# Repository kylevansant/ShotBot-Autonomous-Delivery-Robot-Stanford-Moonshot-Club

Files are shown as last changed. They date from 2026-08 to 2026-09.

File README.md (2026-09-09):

# ShotBot

**Stair-Climbing Robotic Delivery Platform**  
Developed through the Stanford Moonshot Club

ShotBot is a team-developed mechatronics project focused on building a mobile delivery robot capable of traversing stairs. The project began as a broader autonomous-delivery concept, originally called **SCARD — Stair Climbing Autonomous Robot Delivery**, and evolved into a working prototype centered on the core mechanical and electrical challenges of stair climbing.

The completed platform combines a tracked drivetrain, an articulated front stair-climbing mechanism, custom mechanical components, a custom electrical interconnect PCB, and ESP32-based motor control. The final prototype is operated with a Bluetooth gamepad and demonstrates controlled driving and functional stair climbing. Autonomous navigation, LiDAR-based perception, and additional sensing were investigated during development but were not integrated into the final operating system.

The repository documents the full engineering process, including mechanical design, electrical architecture, embedded firmware, design references, prototype testing, and development history.

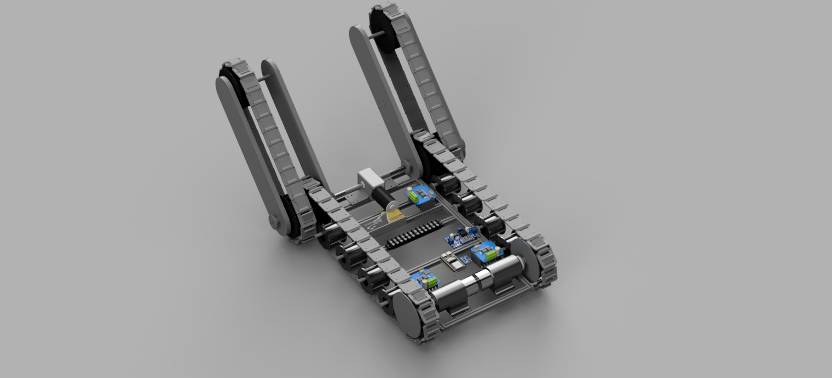
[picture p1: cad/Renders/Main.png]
ShotBot CAD render


## Demonstration

The final prototype successfully demonstrated the primary goal of the project: climbing a staircase using its tracked drivetrain and articulated front mechanism.

https://github.com/user-attachments/assets/51ea6069-b447-48b8-9718-07221bc402e1

Additional development and testing footage is available in the [`media/`](media/) directory.

## Mechanical Design

The mechanical system was designed primarily in Autodesk Fusion 360. ShotBot uses a tracked drivetrain together with an articulated front mechanism intended to improve engagement with stair surfaces and assist the robot during transitions onto and off of a staircase.

Mechanical development included the main chassis, drivetrain components, sprockets, tread elements, motor mounts, front flipper components, sensor mounting concepts, and multiple design revisions retained in the repository to document the evolution of the system.

The repository includes native Fusion 360 assembly files, STEP exports, custom-part models, and rendered views of the completed assembly.

For detailed mechanical documentation, see the [`cad/`](cad/) directory.

## Electrical System

ShotBot is powered by a 3S LiPo battery and uses three independent BTS7960 motor-driver channels controlled by an ESP32 DevKit. The electrical system separates the high-current motor-power paths from the low-voltage control electronics and uses individually fused branches for the major loads.

The system was developed incrementally, beginning with breadboard-based integration and subsystem testing before being consolidated into a custom interconnect PCB designed in Altium Designer. The final PCB was fabricated, installed on the robot, and used successfully during operation.

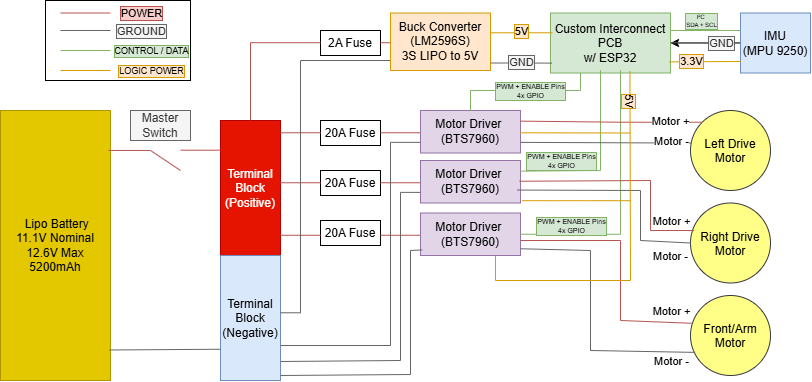
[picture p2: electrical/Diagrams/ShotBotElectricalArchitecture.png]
ShotBot electrical architecture


The electrical architecture above shows the relationship between the battery, fused power-distribution branches, buck-converted logic supply, ESP32 controller, motor drivers, and sensor interfaces used in the final prototype.

The custom PCB organizes the interfaces between the ESP32, motor drivers, IMU, and low-voltage power system while reducing point-to-point wiring in the final prototype.

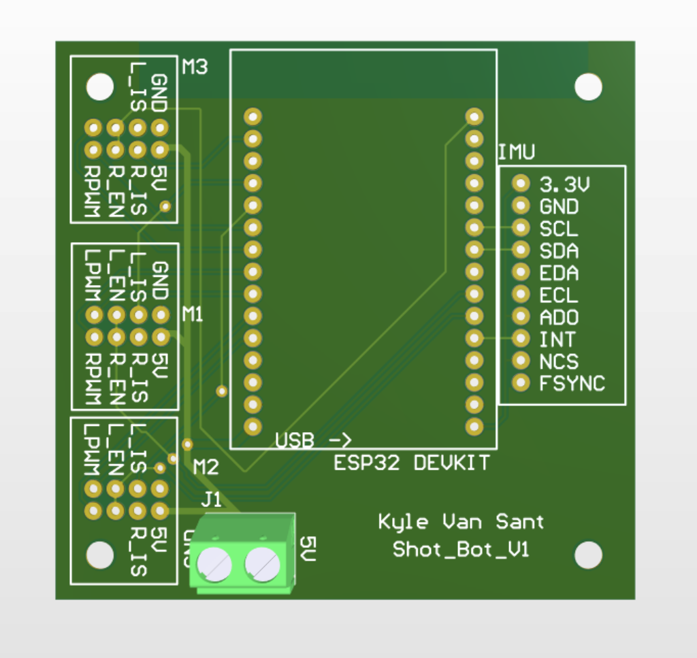
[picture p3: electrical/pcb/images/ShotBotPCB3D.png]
ShotBot PCB render


For schematics, PCB source files, Gerbers, photographs, and additional electrical documentation, see the [`electrical/`](electrical/) directory.

## Firmware and Control

The final robot is controlled by an ESP32 using firmware written with the Arduino framework. Bluetooth gamepad support is provided through Bluepad32.

The firmware independently controls the left drivetrain motor, right drivetrain motor, and front stair-climbing motor through three BTS7960 H-bridges. Tank-style joystick control is used for the drivetrain, while the front mechanism is controlled independently from the gamepad shoulder buttons.

The final control software also includes PWM output limits, joystick deadzone handling, motor-driver enable control, and controller-disconnect fail-safe behavior. The firmware in the repository is the integrated code used on the working prototype rather than the temporary subsystem-test sketches used during development.

For the final control code and implementation details, see the [`firmware/`](firmware/) directory.

## Testing and Prototype Development

ShotBot was developed through repeated subsystem and integration testing rather than as a single final build. Testing included individual motor operation, tread behavior, drivetrain motion, front-mechanism control, electrical integration, controller operation, sensor experiments, and stair-climbing trials.

The [`media/`](media/) directory contains video documentation from these stages of development. This footage is retained to show the progression from early component testing through the completed stair-climbing prototype.

The [`tests/`](tests/) directory is reserved for project testing documentation and related material.

## Project Documentation

Supporting project records are maintained in the [`docs/`](docs/) directory. These include the project bill of materials, the original SCARD project pitch, and technical references used during development.

One of the primary design references was the 2023 IEEE Access review *Stair-climbing Robots: a Review on Mechanism, Sensing, and Performance Evaluation*. Its discussion of tracked stair-climbing architectures and articulated flippers helped inform the team's investigation of a tracked platform with a front articulated mechanism.

The original SCARD presentation is retained as historical documentation because it captures the initial project goals, including autonomous navigation, LiDAR sensing, camera integration, stair climbing, and delivery functionality. The final ShotBot prototype intentionally represents a narrower completed scope focused on the mechanical platform, electrical integration, embedded motor control, and reliable stair-climbing operation.

## Repository Organization

The major project sections are organized as follows:

- [`cad/`](cad/) — mechanical CAD, custom parts, assembly files, and renders
- [`electrical/`](electrical/) — electrical architecture, PCB design, fabrication files, and physical implementation
- [`firmware/`](firmware/) — final ESP32 control firmware and control-system documentation
- [`docs/`](docs/) — project records, bill of materials, original pitch, and design references
- [`media/`](media/) — development, testing, and final demonstration footage

Each major engineering section contains its own README with more detailed technical documentation.

## Team

ShotBot was developed as a team project through the Stanford Moonshot Club.

- **Kyle Van Sant** — Project Lead
- **Joshua Nangle** — Mechanical Lead
- **Gabriel Irazabal** — Electrical Lead
- **Griffin Wright** — Dynamics & Analysis Lead

## Project Status

ShotBot reached the working-prototype stage as a remotely controlled stair-climbing delivery platform. The completed system demonstrated integrated mechanical, electrical, and embedded-control functionality, including independent drivetrain control, operation of the front stair-climbing mechanism, and successful stair traversal.

More advanced autonomy concepts were explored during the project, including LiDAR, IMU feedback, and sensor mounting, but were not incorporated into the final operating prototype.

## Development History

The project began as **SCARD — Stair Climbing Autonomous Robot Delivery**, a concept for a delivery robot intended to combine autonomous navigation with the ability to move between floors using conventional stairs.

Early development focused on understanding existing stair-climbing robot architectures and identifying a mechanism that could be manufactured within the team's available resources. Research into tracked robots and articulated flipper systems helped guide the mechanical direction of the project.

From there, development progressed through mechanical CAD and prototype fabrication, drivetrain and tread testing, electrical breadboarding, ESP32 motor-control development, custom PCB design, controller integration, and full-system testing. LiDAR and IMU hardware were also investigated as part of the original sensing and autonomy direction.

As the project matured, the team narrowed the final scope to prioritize completion of a reliable physical platform. The resulting ShotBot prototype used Bluetooth teleoperation rather than autonomous navigation, while retaining the tracked stair-climbing architecture and integrated electrical system developed through the project.

The final stage of development demonstrated the complete robot driving under remote control and successfully climbing stairs, validating the primary mechanical objective that motivated the project.

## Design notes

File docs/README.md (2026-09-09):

# ShotBot Project Documentation

This directory contains supporting project-level documentation for **ShotBot**, a stair-climbing delivery robot developed as part of the Stanford Moonshot Club.

Detailed mechanical, electrical, and firmware documentation is maintained in their respective directories. This folder contains broader project records, including procurement information, historical planning material, and technical references that informed the design.

---

## Bill of Materials and Project Costs

[`Shotbot_BOM.xlsx`](Shotbot_BOM.xlsx)

This spreadsheet contains component procurement and cost records accumulated throughout ShotBot development.

It includes:

- Major mechanical and electrical components
- Component quantities and purchase costs
- Supplier and product references
- Prototype cost tracking
- Components used during earlier design iterations
- Components considered for future revisions

Because the spreadsheet was maintained throughout the development process, some listed components were replaced, removed from the final design, or never incorporated into the completed prototype.

The document is retained as a record of the project's hardware selection, procurement, and iterative development process.

---

## Original SCARD Project Pitch

[`scard_original_project_pitch.pdf`](scard_original_project_pitch.pdf)

This presentation reflects the team's original project concept and intended scope during the early development of ShotBot.

The project was initially proposed as **SCARD — Stair Climbing Autonomous Robot Delivery**. The original concept included planned capabilities such as:

- Autonomous navigation
- LiDAR-based environmental sensing
- Camera integration
- Stair climbing
- Tracked locomotion
- Item transportation

As development progressed, the project scope was narrowed to prioritize the mechanical stair-climbing system, electrical integration, and completion of a reliable working prototype.

The completed ShotBot platform therefore used **Bluetooth teleoperation rather than autonomous navigation**.

The presentation is retained as historical documentation of the project's original goals and design direction and should not be interpreted as a description of the final implemented system.

---

## Design References

The following literature was used during development to evaluate existing approaches to stair-climbing robotics and inform the mechanical architecture of ShotBot.

### Stair-Climbing Robot Mechanisms

[`References/stair_climbing_robots_review.pdf`](References/stair_climbing_robots_review.pdf)

**T. Seo, S. Ryu, J. H. Won, Y. Kim, and H. S. Kim,  
"Stair-climbing Robots: a Review on Mechanism, Sensing, and Performance Evaluation,"  
IEEE Access, 2023.  
DOI: 10.1109/ACCESS.2023.3286871**

This review surveys several major classes of stair-climbing robots, including:

- Tracked robots
- Legged robots
- Wheel-linkage robots
- Wheel-legged robots

The paper was particularly relevant to the development of ShotBot's **tracked stair-climbing architecture**.

Its discussion of one-body tracked robots with articulated flippers helped inform the decision to use a front articulated mechanism in conjunction with the main tracks. The reviewed mechanisms demonstrate how flippers can increase track contact with stairs, assist with transitions onto and off of staircases, and reduce the risk of tip-over during stair traversal.

The ShotBot design was subsequently adapted around the project's own mechanical requirements, available actuators, manufacturing methods, and prototype constraints.

This reference is included to document the prior research that informed the team's mechanical design decisions rather than as work produced by the ShotBot team.

The included author version is distributed under the **Creative Commons Attribution-NonCommercial-NoDerivatives 4.0 International License** and is retained unmodified. :contentReference[oaicite:0]{index=0}

---

## Project Evolution

ShotBot changed significantly between the initial proposal and the completed prototype.

The general project progression was:

```text
Original SCARD Concept
        │
        │  Autonomous stair-climbing delivery robot
        │
        ▼
Mechanical Architecture Development
        │
        │  Tracked locomotion + articulated stair mechanism
        │
        ▼
Electrical Prototyping
        │
        │  Breadboard testing + ESP32 motor control
        │
        ▼
Custom PCB Integration
        │
        │  Altium-designed interconnect PCB
        │
        ▼
Final ShotBot Prototype
        │
        │  Bluetooth teleoperation
        │  Independent motor control
        │  Functional stair climbing
        ▼
Working Prototype
```

Autonomous navigation, LiDAR integration, and camera-based perception remained part of the original design direction but were not implemented in the final version due to project scope.

The project instead focused on successfully demonstrating the mechanical and electrical systems required for a remotely operated stair-climbing delivery platform.

---

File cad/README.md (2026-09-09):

# ShotBot CAD

This directory contains the mechanical design files for **ShotBot**, a stair-climbing delivery robot developed through the Stanford Moonshot Club.

The mechanical system was designed primarily in Autodesk Fusion 360 and developed through repeated prototyping and testing. The final architecture uses a tracked differential-drive base combined with a pair of articulated tracked front flippers. The flippers are mechanically synchronized and are used to control how the robot engages with and transitions onto stairs.

Native Fusion 360 assemblies, STEP exports, custom part files, and rendered views are included to document both the final configuration and the design iterations that led to it.

## Main Assembly

ShotBot main assembly render

The final mechanical assembly combines three major subsystems:

- A left and right tracked drivetrain for normal driving and differential steering
- Two articulated front flippers with their own tracked loops
- A shared flipper-actuation system that rotates both front arms together

The design was intended to keep the stair-climbing mechanism mechanically simple while allowing the front of the robot to change geometry during stair approach and transition.

## Mechanical Architecture

### Main Tracked Drivetrain

ShotBot uses two independent main track loops, one on each side of the chassis.

Each side is powered by a rear drive motor connected to the rear sprocket. The front and rear sprockets are the same diameter, while the rear sprocket functions as the driven sprocket. The remaining sprockets and rollers support and guide the track.

Independent left and right drive control allows the robot to use tank-style steering on flat surfaces.

Track tension is set primarily by the spacing of the sprockets and rollers rather than by a separate active tensioning mechanism.

### Articulated Front Flippers

The front of the robot uses two tracked flipper arms, one on each side.

The left and right flippers are mechanically linked and rotate together. A dual-shaft worm-gear motor drives two rods extending toward the left and right sides of the chassis. These rods are connected through shaft couplers to the flipper assemblies.

Using one motor to control both flippers kept the two sides synchronized and reduced the amount of independent actuation hardware required.

The worm-gear drive also provided a compact method for producing the torque needed to reposition the flippers while keeping the actuation system inside the chassis.

### Coupled Track System

The main drivetrain track and the flipper track are implemented as two separate loops on each side of the robot.

The loops are mechanically coupled through the shared front sprocket geometry. When the main drive motor powers the base track, rotation at the front sprocket also drives the track around the articulated flipper.

This means the flipper tracks do not require separate drive motors. The rear drive motor provides propulsion for both the main track loop and the flipper track loop, while the front worm-gear motor changes only the angular position of the flipper arms.

This separation between **track propulsion** and **flipper articulation** was one of the central mechanical features of the design.

## Stair-Climbing Sequence

The stair-climbing process relies on coordinated use of the drive tracks and front flippers.

At a high level, the sequence is:

1. The robot approaches the staircase using the main drivetrain.
2. The flippers are positioned to engage the first stair.
3. The main tracks continue driving forward, which also drives the flipper track loops.
4. The flippers are rotated as needed to help lift and guide the front of the chassis onto the staircase.
5. Once the main tracks establish contact with the stairs, the robot continues climbing using the combined track contact area.
6. The flippers can be repositioned again during the final transition off the staircase.

The tracked flippers increase the effective contact geometry at the front of the robot and help reduce the abrupt transition that would otherwise occur between flat-ground driving and stair engagement.

## Track Support Rollers

The support rollers underneath the chassis became one of the most important parts of the mechanical design.

The printed tracks deform under the weight of the robot. Without sufficient support, the track can deflect upward enough for the chassis itself to contact the edge of a stair. The rollers provide intermediate support underneath the track so that the robot's weight is carried through the track and roller system rather than directly by the chassis.

This subsystem required significant iteration. Approximately four to five roller-holder designs were tested before reaching a configuration that could support the robot without excessive bending or failure.

The roller holders therefore represent a relatively small part geometrically, but they were critical to making the final stair-climbing system function reliably.

## Mechanical Development and Iteration

The final design was the result of repeated mechanical revisions rather than a single CAD pass.

Several areas required substantial iteration during development.

### Roller Holders

Early roller-holder designs were not stiff enough to support the chassis loads generated during stair climbing. Some versions bent or failed under the robot's weight.

Multiple revisions were made to improve stiffness, load transfer, and support of the track until the roller system could reliably keep the chassis clear of the stair edges.

### Shaft Couplers

Early couplers were 3D printed and used a snap-style attachment concept.

These parts were unable to transfer sufficient torque reliably. Under load, the couplers could slip rather than maintaining a rigid connection between the motor-driven shaft and the mechanism.

The coupler design therefore became an important mechanical limitation and was revised as the system developed.

### Sprocket Interfaces

Several sprocket versions were developed with different attachment methods to the drive shafts and couplers.

The main challenge was not the sprocket geometry itself, but creating a connection that could transmit drivetrain torque reliably while remaining manufacturable with the tools and materials available to the team.

Earlier sprocket variants are retained in the repository because they document this progression.

### Front Motor Packaging

The front flipper motor and shaft system also created packaging challenges.

The worm-gear motor, couplers, shafts, bearings, and surrounding electrical hardware all had to fit within the chassis while remaining aligned with the left and right flipper assemblies.

Several motor-bracket revisions were required to produce a configuration that was mechanically supported and could be integrated with the rest of the robot.

## Manufacturing Approach

The project relied heavily on additive manufacturing for custom drivetrain and stair-climbing components.

The tread system was inspired in part by **James Bruton's 3D-printed tank tread designs** and was adapted for the geometry, loading, and stair-climbing requirements of ShotBot.

3D printing made it possible to iterate rapidly on:

- Track links
- Sprockets
- Roller holders
- Motor brackets
- Flipper-arm components
- Couplers and shaft interfaces
- Sensor and accessory mounts

This manufacturing approach allowed the team to test several mechanical concepts quickly, but it also introduced limitations in stiffness, torque transmission, and wear that became apparent during full-system testing.

## Design Tradeoffs and Lessons Learned

The final architecture successfully demonstrated stair climbing, but the development process also exposed several areas that could be improved in a future revision.

A belt-driven drivetrain would likely simplify some of the torque-transfer and shaft-coupling challenges encountered with the printed sprocket and coupler system. In particular, the drive-motor interfaces could potentially be made easier to manufacture, align, and service using a conventional belt-and-pulley transmission.

In contrast, using a **single motor to actuate both front flippers** proved to be a useful simplification. Mechanically linking the two sides kept the flippers synchronized and reduced the number of actuators, motor drivers, and control channels required for the stair-climbing mechanism.

A future design would likely retain synchronized flipper actuation while reconsidering portions of the main drivetrain power transmission and track-support structure.

## CAD Organization

### Assemblies

The `Assemblies/` directory contains the primary ShotBot mechanical assembly.

- `Assemblies/Source/` contains the native Fusion 360 assembly.
- `Assemblies/Step/` contains an exported STEP version for use in other CAD platforms.

### Custom Parts

The `Custom_parts/` directory contains the custom components developed during the project, including both final parts and earlier design iterations.

These files include components associated with:

- Drive sprockets
- Bearing and roller sprockets
- Roller holders
- Flipper arms
- Flipper sprockets
- Motor brackets
- Tread links
- Shaft and coupler interfaces
- LiDAR mounting concepts

Some older parts are intentionally retained even when they do not appear in the final assembly. They document the mechanical iteration process and the design problems encountered during prototyping.

### Renders

The `Renders/` directory contains views of the assembled robot for inspection without CAD software.

Available views include:

- `Main.png`
- `Isometric.png`
- `Front.png`
- `Side.png`
- `Top.png`

## LiDAR Mount

The custom-parts directory includes a preliminary LiDAR mount created during the period when autonomous navigation and environmental sensing were being explored.

The LiDAR system was not incorporated into the final operating prototype. The mount is retained as historical CAD documenting the broader original project scope.

## Third-Party Components

The development assembly included CAD models for commercial off-the-shelf hardware such as motors, bearings, electronics, and other purchased components.

These externally sourced models are included only to represent the physical assembly and packaging constraints. They should not be interpreted as original ShotBot mechanical designs.

## Project Status

The completed mechanical platform reached the working-prototype stage and successfully demonstrated both tracked driving and stair climbing.

The final system validated the central mechanical concept: a tracked base with synchronized articulated tracked flippers can provide the geometry and contact needed for a compact robot to transition onto and climb a staircase.

The repository retains both the completed design and earlier iterations so that the mechanical development process, including unsuccessful concepts and subsequent revisions, remains documented.

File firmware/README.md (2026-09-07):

# ShotBot Firmware

This directory contains the ESP32 firmware used to control **ShotBot**, a stair-climbing delivery robot developed as part of the Stanford Moonshot Club.

The firmware provides Bluetooth gamepad control through the Bluepad32 library and directly controls three BTS7960 motor-driver channels:

- Left drive motor
- Right drive motor
- Front / stair-climbing motor

The firmware contained in this directory was used on the working ShotBot prototype.

---

## Firmware Structure

The ShotBot firmware is intentionally compact and is implemented as a single Arduino sketch.

```text
firmware/
├── README.md
└── ShotBotCode/
    └── ShotBotCode.ino
```

The complete ESP32 control firmware is located at:

`ShotBotCode/ShotBotCode.ino`

The sketch contains the Bluetooth gamepad interface, motor-driver configuration, PWM generation, drivetrain control, stair-climbing motor control, and controller-disconnect safety behavior.

---

## Hardware Interface

The firmware runs on an **ESP32 DevKit** mounted to the custom ShotBot interconnect PCB.

The ESP32 controls three BTS7960 H-bridge motor drivers:

| Motor | Function |
| --- | --- |
| M1 | Left drive motor |
| M2 | Front / stair-climbing motor |
| M3 | Right drive motor |

Each motor driver receives independent forward and reverse PWM signals from the ESP32.

The electrical connections between the ESP32 and the motor drivers are defined by the custom interconnect PCB.

For additional electrical documentation, see:

[`../electrical/`](../electrical/)

---

## ESP32 Pin Assignments

### Motor Enable Pins

| Motor | ESP32 GPIO |
| --- | ---: |
| M1 - Left Drive | GPIO 23 |
| M2 - Front / Stair Climber | GPIO 16 |
| M3 - Right Drive | GPIO 17 |

### Motor PWM Pins

| Motor | LPWM | RPWM |
| --- | ---: | ---: |
| M1 - Left Drive | GPIO 25 | GPIO 26 |
| M2 - Front / Stair Climber | GPIO 27 | GPIO 14 |
| M3 - Right Drive | GPIO 33 | GPIO 32 |

The current firmware uses one shared enable signal per BTS7960 module and independent forward/reverse PWM channels for motor direction and speed control.

---

## Gamepad Control

ShotBot is operated using a Bluetooth-compatible gamepad connected to the ESP32 through the **Bluepad32** library.

The firmware continuously reads the connected controller and converts joystick and button inputs into motor commands.

### Drive Controls

The rear drivetrain uses tank-style control.

| Controller Input | Function |
| --- | --- |
| Left joystick Y-axis | Left drive motor |
| Right joystick Y-axis | Right drive motor |

Each side of the drivetrain is controlled independently, allowing forward motion, reverse motion, and differential turning.

### Stair-Climbing Motor

The front motor controls the stair-climbing mechanism.

| Controller Input | Function |
| --- | --- |
| R1 | Front motor forward |
| L1 | Front motor reverse |
| R1 + L1 | Stop front motor |
| Neither pressed | Stop front motor |

---

## PWM Configuration

The ESP32 LEDC peripheral generates PWM signals for the three BTS7960 motor drivers.

| Parameter | Value |
| --- | ---: |
| PWM frequency | 20 kHz |
| PWM resolution | 8-bit |
| Full PWM range | 0-255 |
| Maximum drive-motor output | 102 / 255 |
| Maximum front-motor output | 255 / 255 |
| Joystick deadzone | 8% |
| Main loop delay | 10 ms |

The two rear drive motors are intentionally limited to approximately **40% of the available PWM range**.

The front stair-climbing motor is permitted to use the full PWM range.

An 8% joystick deadzone is applied around the neutral position to prevent small joystick offsets from causing unintended motor motion.

---

## Motor Control

Motor direction is controlled by driving one BTS7960 PWM channel while holding the opposite channel at zero.

Conceptually:

```text
Positive command  -> Forward PWM active, reverse PWM = 0
Negative command  -> Reverse PWM active, forward PWM = 0
Zero command      -> Both PWM channels = 0
```

All requested motor commands are constrained to the configured maximum PWM value before being written to the motor drivers.

This allows the drivetrain and stair-climbing mechanism to use different output limits while sharing the same motor-control function.

---

## Safety Behavior

The firmware includes several basic fail-safe behaviors intended to prevent unintended motor operation.

### Startup

All BTS7960 enable outputs are disabled during ESP32 initialization.

The motors therefore remain inactive while the controller interface and PWM hardware are being configured.

### Controller Connection

When a supported gamepad connects successfully, the firmware stores the active controller and enables the motor drivers.

### Controller Disconnect

If the Bluetooth controller disconnects:

1. All motor PWM commands are set to zero.
2. All BTS7960 enable outputs are disabled.
3. The robot remains stopped until a controller reconnects.

The main control loop also continuously verifies that a controller remains connected. If no valid controller is available, the firmware repeatedly stops the motors and disables the drivers.

---

## Bluepad32

ShotBot uses **Bluepad32** to provide Bluetooth gamepad support on the ESP32.

The firmware registers callbacks for:

- Gamepad connection
- Gamepad disconnection

Once a controller is connected, joystick axes and shoulder-button states are read continuously in the main loop.

Bluepad32 handles the underlying Bluetooth controller interface, allowing the ShotBot firmware to focus on interpreting commands and controlling the motors.

---

## IMU Development

The ShotBot electrical system also includes an **MPU9250 IMU** connected to the ESP32 over I²C.

The IMU interface was tested during development and produced valid sensor feedback.

The sensor was originally intended to support more advanced feedback and future robot-state estimation. However, because the completed ShotBot prototype was operated remotely, IMU feedback was not required by the final teleoperation firmware.

The final controller sketch therefore focuses on gamepad and motor control rather than closed-loop IMU-based behavior.

Additional IMU hardware information is documented in the electrical section of the repository.

---

## Motor Driver Current Feedback

The BTS7960 current-sense connections were included in the ShotBot electrical hardware and routed through the custom interconnect PCB.

These signals were available for potential current monitoring and future protection or diagnostic functionality, but they were not incorporated into the final motor-control logic used by the working teleoperated prototype.

---

## Development Testing

During development, temporary test sketches were used to validate individual parts of the electrical and control system before the final firmware was integrated.

Testing included:

- Individual BTS7960 motor-driver operation
- Motor direction control
- PWM speed control
- Three-motor integration
- Bluetooth gamepad communication
- Controller disconnect behavior
- MPU9250 I²C communication
- Final integration with the custom interconnect PCB

These development-only test sketches were not retained.

The repository therefore contains the final integrated firmware used on the working ShotBot prototype rather than the temporary subsystem test programs.

---

## Building and Uploading

The firmware was developed for an ESP32 using the Arduino framework.

### Requirements

- ESP32-compatible Arduino development environment
- ESP32 board support package
- Bluepad32 library
- USB connection to the ESP32 DevKit

### Upload Procedure

1. Install an Arduino-compatible ESP32 development environment.
2. Install the required ESP32 board support package.
3. Install Bluepad32 and its required ESP32 support.
4. Open:

   `ShotBotCode/ShotBotCode.ino`

5. Select the appropriate ESP32 DevKit target.
6. Select the correct serial port.
7. Compile the sketch.
8. Upload the firmware to the ESP32.
9. Open the serial monitor at **115200 baud** if connection-status messages are desired.
10. Pair a compatible Bluetooth gamepad with the ESP32.

Once a controller connects successfully, the motor drivers are enabled and ShotBot can be operated using the controls described above.

Exact development-tool and library versions were not retained from the original development environment and are therefore not specified here.

---

## Serial Output

The firmware uses a serial baud rate of:

```text
115200 baud
```

Serial output provides basic controller-status information, including:

```text
Bluepad32 ready. Pair a controller to begin.
Controller connected.
Controller disconnected.
```

The serial connection is not required during normal robot operation.

---

## Firmware Scope

The final ShotBot firmware was designed for **reliable remote operation of the completed prototype**.

The implemented firmware provides:

- Bluetooth gamepad control
- Independent left and right drivetrain control
- Bidirectional stair-climbing motor control
- PWM output limiting
- Joystick deadzone handling
- Motor-driver enable control
- Controller-disconnect fail-safe behavior

More advanced features considered during development, including IMU-based feedback and motor-current monitoring, were electrically supported but were not required for the final teleoperated implementation.

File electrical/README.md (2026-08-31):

# ShotBot Electrical System

This directory contains the electrical design and documentation for **ShotBot**, a stair-climbing delivery robot developed as part of the Stanford Moonshot Club.

The electrical system was designed around a 3S LiPo battery, three independent BTS7960 motor-driver channels, an ESP32 DevKit, and a custom interconnect PCB. The system was developed incrementally through initial component layout, breadboard-based validation, PCB design, and final integration onto the robot.

The custom PCB and associated electrical architecture were successfully installed and operated on the ShotBot prototype.

---

## System Architecture

ShotBot Electrical Architecture

The electrical system is divided into two primary sections:

- **High-current motor power**, supplied directly from the battery rail through individually fused motor-driver branches
- **Low-voltage control electronics**, powered through an LM2596S buck converter and distributed through the custom interconnect PCB

### Power Architecture

ShotBot is powered by a **3S 5200 mAh LiPo battery** with a nominal voltage of 11.1 V and a maximum fully charged voltage of 12.6 V.

The battery is connected through a **master power switch** to positive and negative terminal blocks that form the main power-distribution rails.

Each major load is protected by an individual branch fuse.

| Branch | Protection | Load |
| --- | ---: | --- |
| Left drive | 20 A | BTS7960 + rear-left drive motor |
| Right drive | 20 A | BTS7960 + rear-right drive motor |
| Front / arm drive | 20 A | BTS7960 + front motor |
| Control electronics | 2 A | LM2596S + low-voltage electronics |

The terminal blocks provide centralized positive and ground distribution while minimizing exposed electrical connections. Most high-current connections are enclosed or terminated using screw terminals.

---

## Motor Control

ShotBot uses **three BTS7960 H-bridge motor-driver modules**, allowing the ESP32 to independently control three motor channels.

The drivers control:

1. Rear-left drive motor
2. Rear-right drive motor
3. Front / stair-climbing motor

The two rear drive motors are **ServoCity 118 RPM HD Premium Planetary Gear Motors**.

Each BTS7960 receives:

- Battery power from its individually fused branch
- 5 V logic power and ground
- PWM control signals from the ESP32
- Enable signals from the ESP32

The motor-driver current-sense connections were also routed in hardware as part of the electrical architecture.

---

## Low-Voltage Power System

A dedicated **2 A fused branch** supplies an LM2596S buck converter.

The buck converter reduces the battery voltage to **5 V** for the low-voltage control system.

The 5 V rail powers:

- ESP32 DevKit
- BTS7960 logic interfaces
- Custom interconnect PCB connections

The ESP32 provides the 3.3 V supply used by the MPU9250 IMU.

This arrangement separates the low-voltage control electronics from the high-current motor branches while maintaining a common electrical ground across the system.

---

## Custom Interconnect PCB

ShotBot uses a custom PCB to organize the electrical connections between the ESP32, motor drivers, IMU, and power system.

The board was designed in **Altium Designer** and was manufactured, installed, and successfully operated on the robot.

The PCB does not contain active control circuitry. Instead, it functions as an **interconnect and signal-distribution board**, replacing a large number of point-to-point wire connections with fixed PCB routing and labeled headers.

The board provides connections for:

- ESP32 DevKit
- Three BTS7960 motor drivers
- MPU9250 IMU
- 5 V logic power
- 3.3 V sensor power
- Common ground
- Motor-driver PWM signals
- Motor-driver enable signals
- Motor-driver current-sense signals
- I²C communication

The ESP32 mounts directly to header pins on the PCB, while labeled headers provide the external connections to the motor drivers and sensor.

Because the signal routing is defined directly by the PCB, the Altium schematic and PCB layout serve as the primary wiring and interconnect reference for the electrical system.

---

## PCB Design Files

ShotBot Electrical Architecture

The `pcb/` directory contains the design and fabrication files associated with the custom interconnect board.

### Source

`pcb/source/`

Contains the editable Altium project files, including:

- Altium PCB project
- PCB layout
- Schematic
- Fabrication output configuration

### Libraries

`pcb/libraries/`

Contains the custom Altium schematic-symbol and PCB-footprint libraries created for interfaces used by the interconnect board, including:

- ESP32 carrier
- BTS7960 motor drivers
- MPU9250 IMU

### Gerbers

`pcb/gerbers/`

Contains the Gerber and drill outputs used for PCB fabrication.

These include the relevant:

- Top and bottom copper layers
- Solder-mask layers
- Silkscreen / overlay layers
- Paste layers
- Mechanical / board-outline data
- Drill data

### PCB Images

`pcb/images/`

Contains visual documentation of the PCB, including Altium layout screenshots and 3D board views. These images allow the board design to be inspected without requiring Altium Designer.

---

## MPU9250 IMU

An **MPU9250 inertial measurement unit** was connected to the ESP32 over I²C using the SDA and SCL lines.

The IMU was electrically integrated and tested successfully, and valid sensor feedback was obtained from the device.

The sensor was originally intended to support more advanced robot-state estimation and future control capabilities. However, ShotBot ultimately operated as a remotely controlled platform, where IMU feedback provided limited practical benefit to the final control system.

The IMU therefore remained part of the electrical architecture but was not required for normal operation of the final remote-controlled version.

---

## Physical Implementation

### Final Electrical System

The final electrical system installed on ShotBot is shown below.

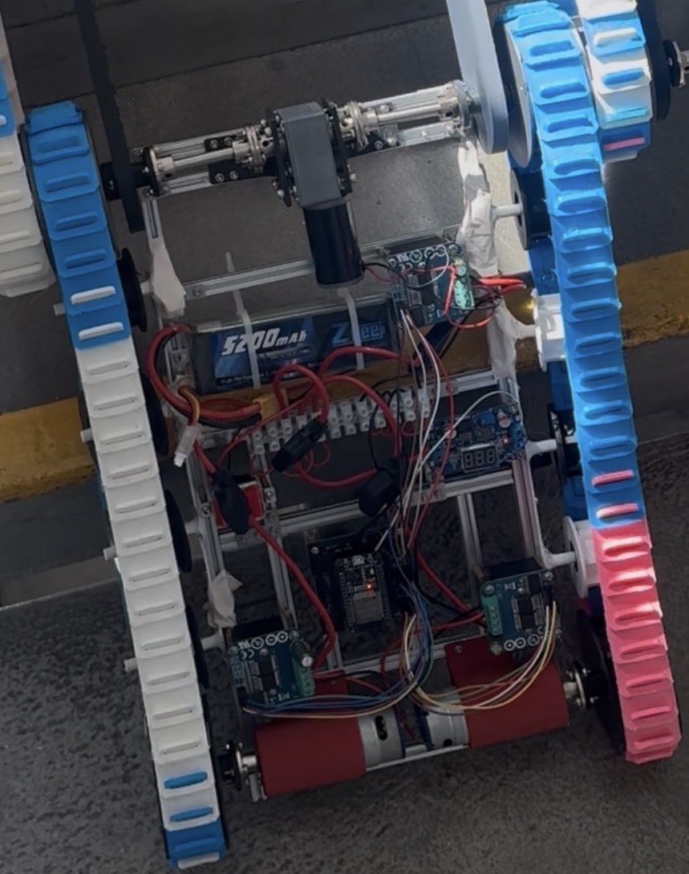
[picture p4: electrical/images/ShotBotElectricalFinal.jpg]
Final electrical system


This implementation includes the battery power-distribution system, master power switch, motor drivers, buck converter, custom interconnect PCB, and ESP32 controller.

---

## Electrical Development Process

The electrical system was developed incrementally rather than being implemented directly as a finished PCB.

Development progressed through several stages:

1. Initial architectural component layout
2. Breadboard-based electrical integration
3. Functional testing of the ESP32 and motor-driver interfaces
4. Custom PCB design in Altium Designer
5. PCB fabrication and testing
6. Final integration onto the ShotBot prototype

### Initial Component Layout

The initial layout was used to establish the intended placement of the major electrical components before permanent integration onto the robot.

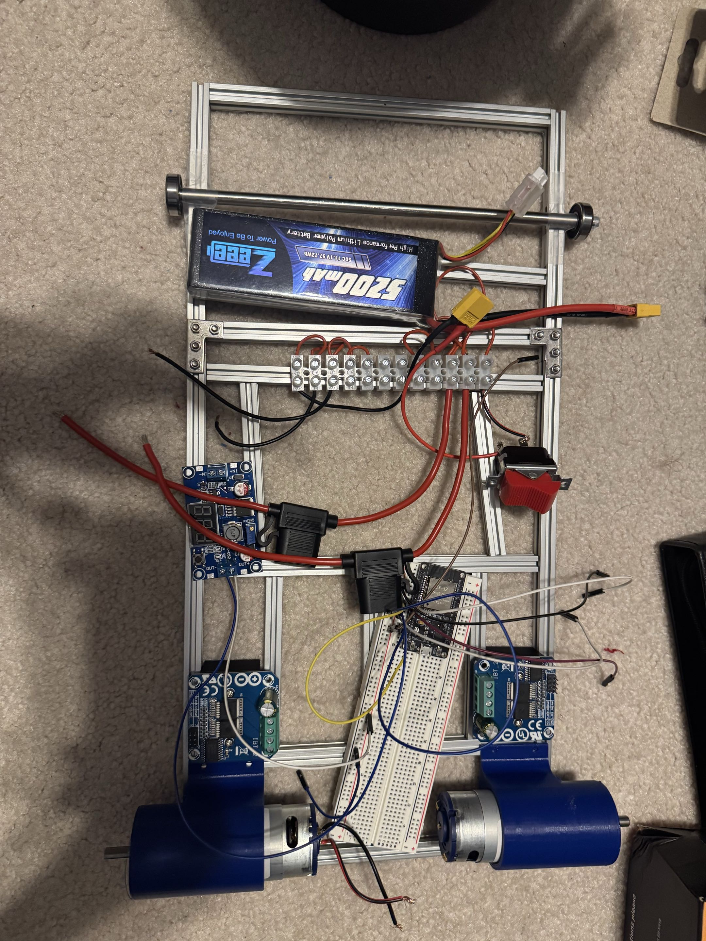
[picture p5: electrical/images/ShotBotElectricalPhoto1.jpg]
Initial component layout


### Breadboard-Based Prototype

Before designing the custom PCB, the control system was assembled and validated using a breadboard-based prototype.

These early development stages were used to test the ESP32, motor-driver interfaces, power distribution, and overall system connectivity.

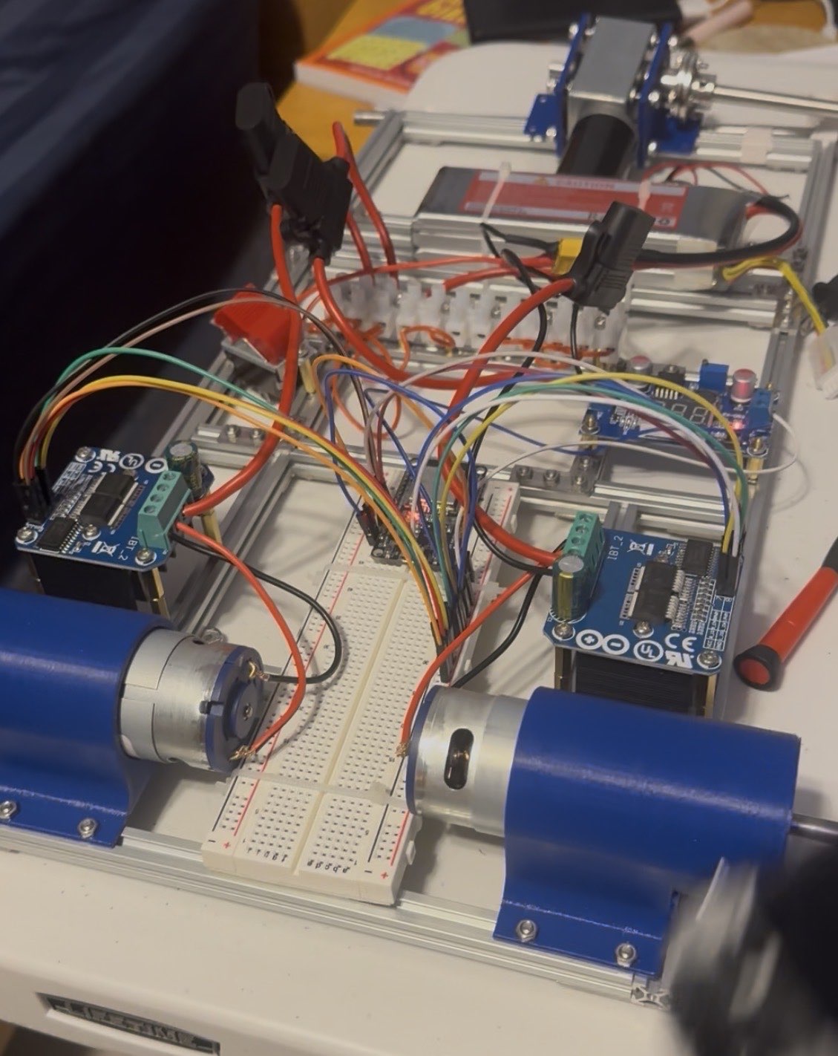
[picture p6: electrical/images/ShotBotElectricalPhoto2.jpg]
Breadboard prototype 1


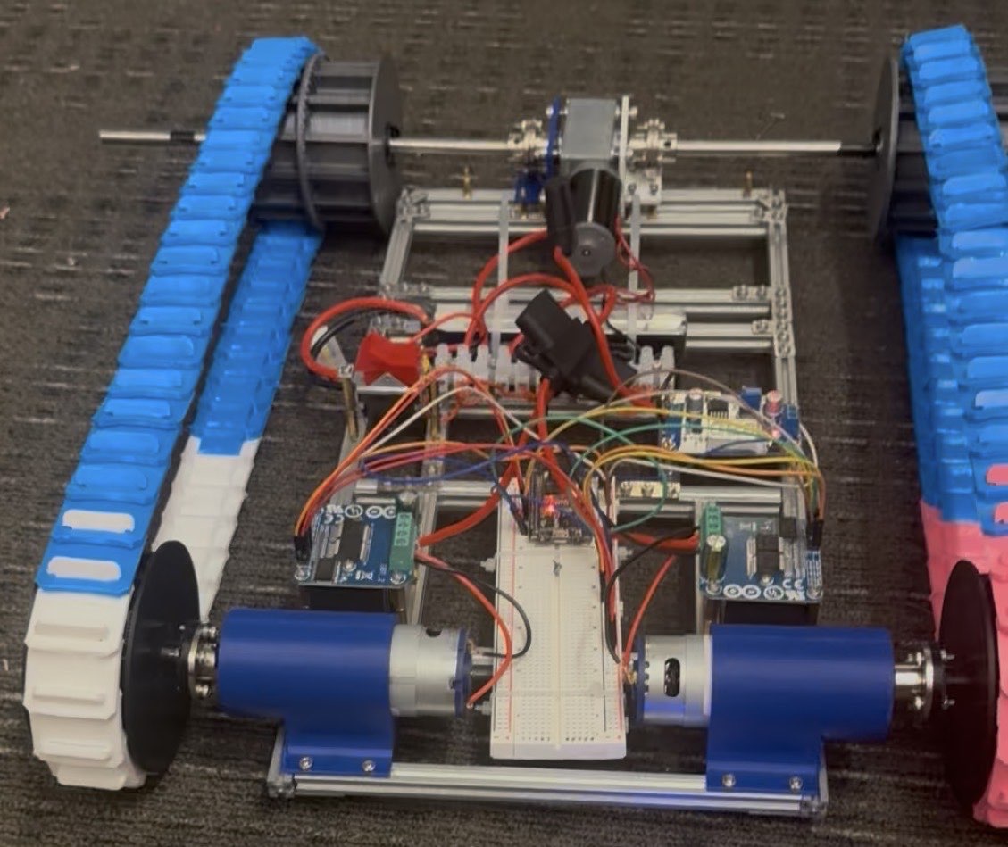
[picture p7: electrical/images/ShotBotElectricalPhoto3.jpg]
Breadboard prototype 2


### Final PCB Integration

After validating the system architecture on the breadboard, the electrical wiring was consolidated onto the custom interconnect PCB and installed on the robot.

This reduced point-to-point wiring and provided a cleaner, more repeatable electrical implementation.

---

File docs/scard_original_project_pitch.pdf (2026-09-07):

# Stair ClimbingAutonomous RobotDelivery (SCARD)

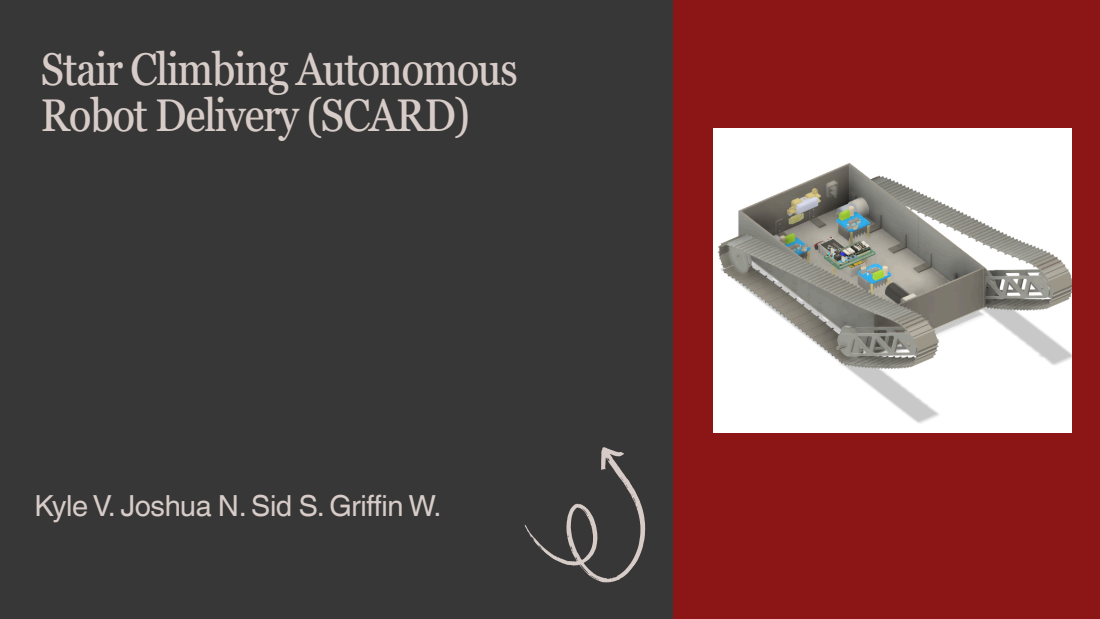
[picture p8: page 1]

Kyle V. Joshua N.Sid S. Griffin W.

2

# Purpose of SCARD

### Overcoming Delivery Challenges in Dorms

Dorm deliveries are often inefficient due to stairs and limited access.Shot Bot addresses these obstacles, providing a streamlined solution for timely and effective deliveries within campus environments.

3

# Core Features

### Key functionalities of SCARD

### Autonomous Navigation

Shot Bot utilizes advanced sensors and algorithms to navigate autonomously, allowing it to efficiently traverse complex environments within dorms without human intervention.

### Stair Climbing

Engineered with innovative flippertrack mechanics, SCARD can conquer stairs, ensuring smooth delivery regardless of elevation changes encountered in dormitory buildings.

### Tracked Motion

The robot's tracked motion system provides stability and traction, enabling it to maneuver over various surfaces while maintaining balance and avoiding potential obstacles.

# Mechanical System Overview

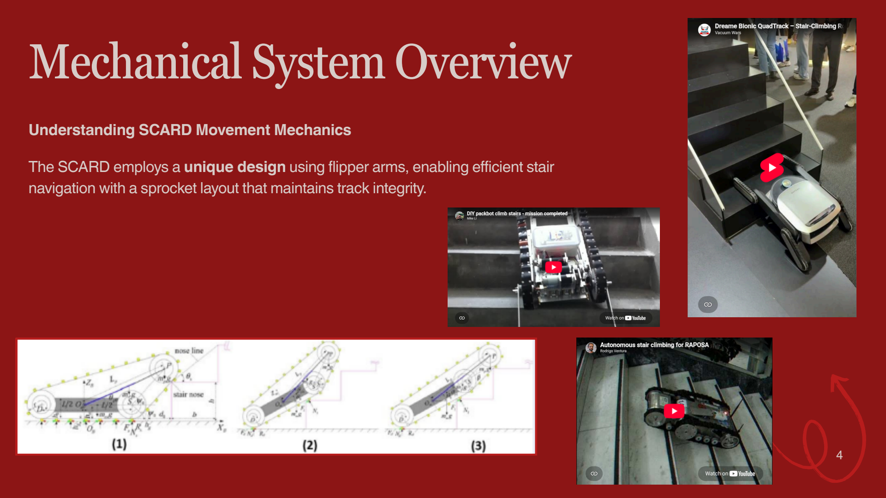
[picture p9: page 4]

4

### Understanding SCARD Movement Mechanics

The SCARD employs a unique design using flipper arms, enabling efficient stair navigation with a sprocket layout that maintains track integrity.

# Electronics Control Systems

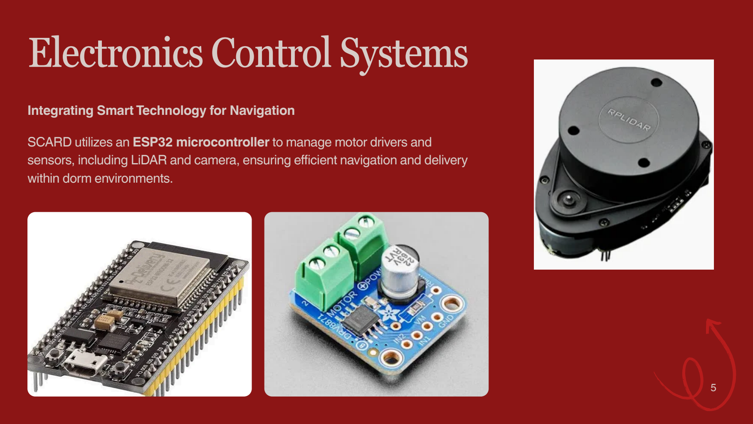
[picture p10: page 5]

5

### Integrating Smart Technology for Navigation

SCARD utilizes an ESP32 microcontroller to manage motor drivers and sensors, including LiDAR and camera, ensuring efficient navigation and delivery within dorm environments.

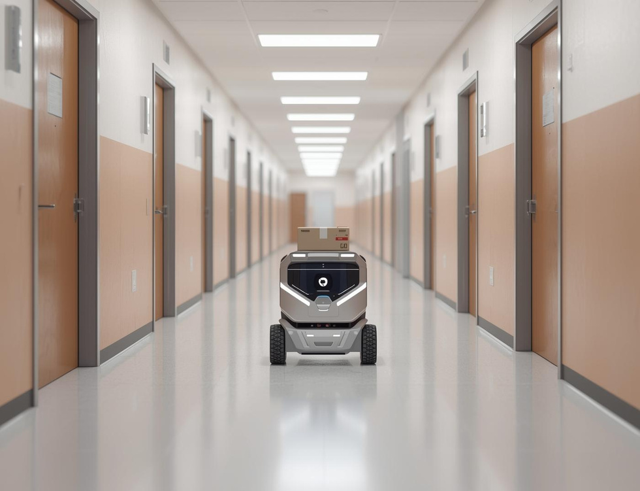
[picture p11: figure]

SCARD streamlines dorm deliveries, ensuring timely and efficient package drop-offs for students.

## Dorm Delivery

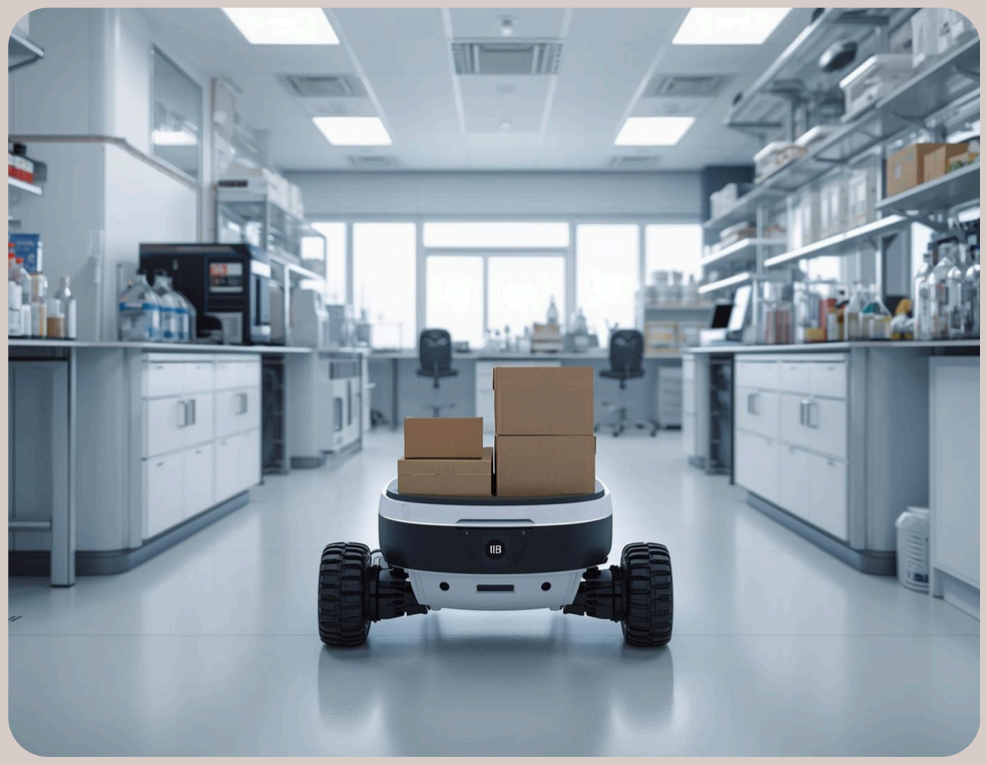
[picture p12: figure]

Used for lab supply transport, SCARD efficiently manages deliveries, enhancing research workflows and productivity.

## Lab Supply Transport

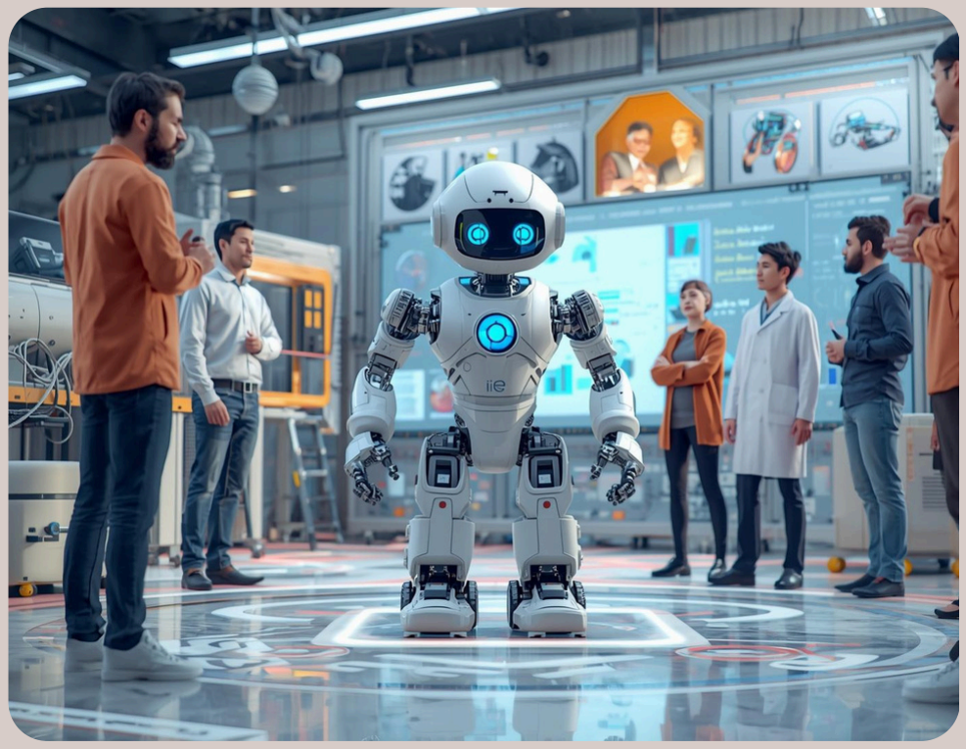
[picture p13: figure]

SCARD serves as a tool in robotics research, contributing to advancements in autonomous navigation technology.

## Robotics Research

# Applications of Shot Bot

# First PrototypeGoals

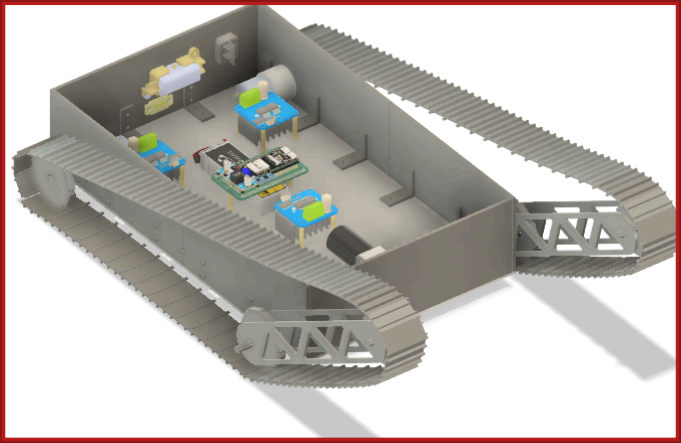
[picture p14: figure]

## Stair Climbing Capability:Designed to effortlessly navigate staircasesfor

use in multi-levelsettings.

## Remote Operability: Controlled remotely for convenient

manipulation and direction.

## Item Transport: Capable of carrying and moving various objects

efficiently.

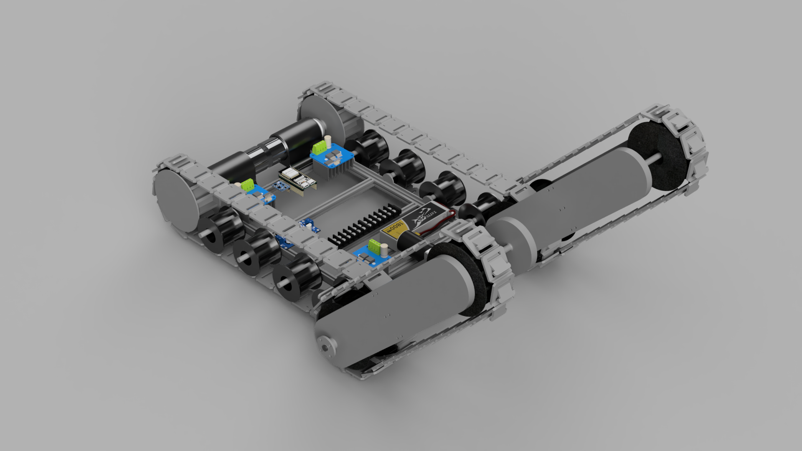
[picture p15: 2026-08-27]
cad/Renders/Isometric.png

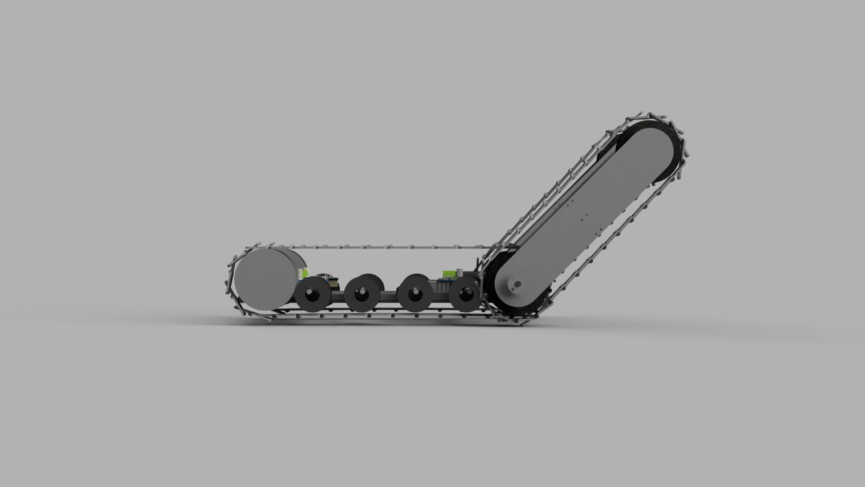
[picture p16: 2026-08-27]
cad/Renders/Side.png

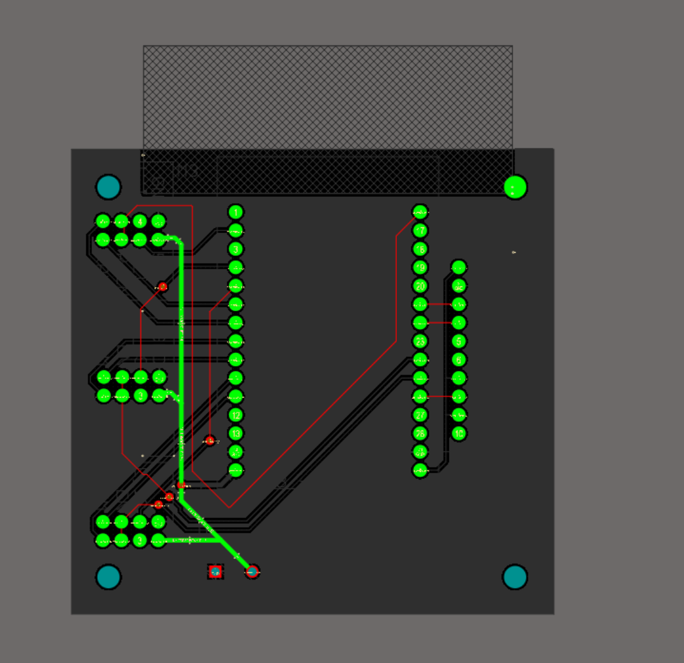
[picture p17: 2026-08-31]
electrical/pcb/images/ShotBotPCBLayer1.png

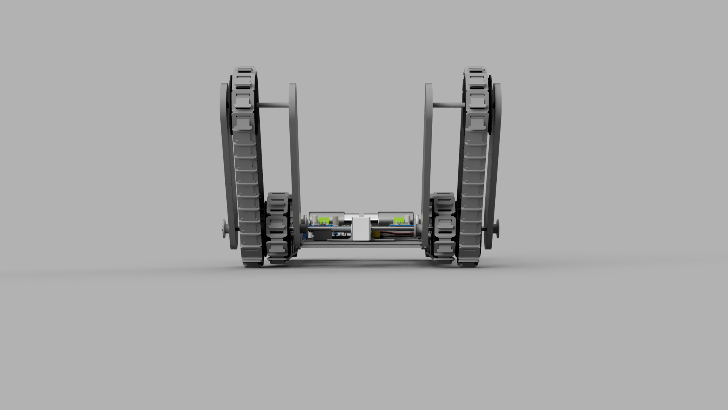
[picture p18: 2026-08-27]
cad/Renders/Front.png

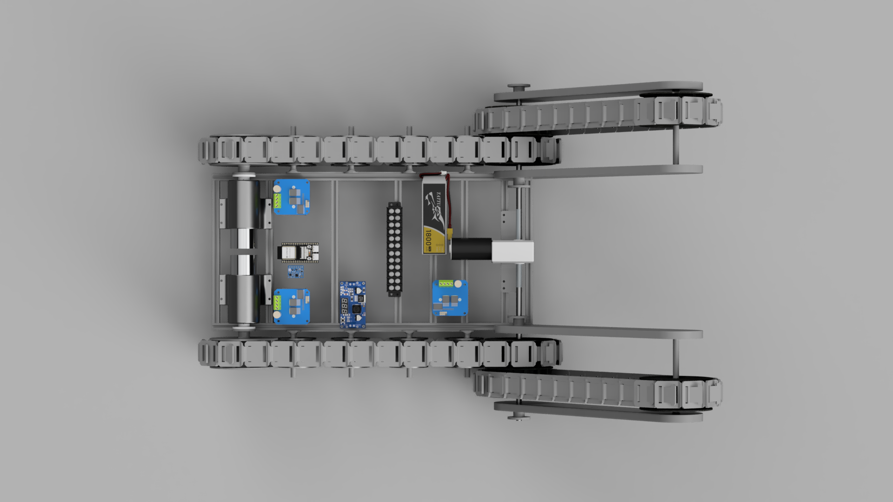
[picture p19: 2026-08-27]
cad/Renders/Top.png

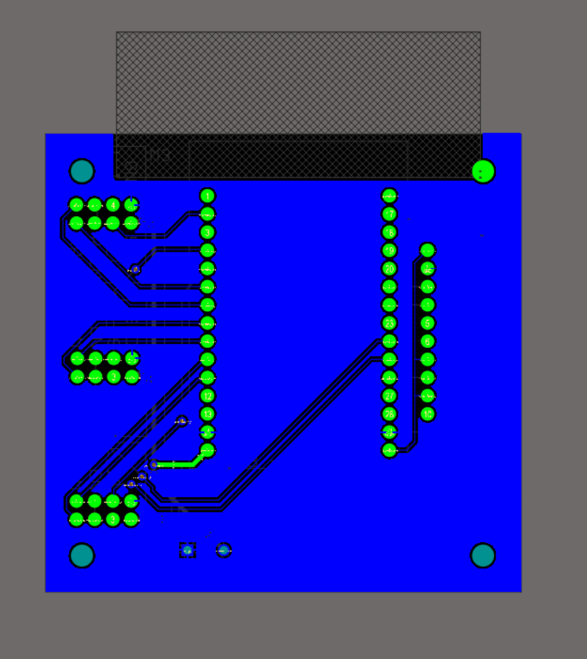
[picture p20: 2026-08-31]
electrical/pcb/images/ShotBotPCBLayer2.png

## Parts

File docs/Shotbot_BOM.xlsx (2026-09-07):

 |  | Item | cost | quantity | total cost | URL
Total Spent | $448.53 | ESP32 | $16.00 | 1 | $16.00 | https://www.amazon.com/ESP-WROOM-32-Development-Microcontroller-Integrated-Compatible/dp/B08D5ZD528
Prototype 1 | $545.07 | Track | $7.00 | 0 | $0.00 | https://www.robotshop.com/products/servocity-48mm-grid-track-24mm-pitch-48mm-width-6-pack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
Prototype 2 | $825.07 | Motors | $40.00 | 2 | $80.00 | https://www.servocity.com/118-rpm-hd-premium-planetary-gear-motor/
 |  | worm gear motor | $27.00 | 1 | $27.00 | https://www.amazon.com/uxcell-Double-Torque-Reduction-Gearbox/dp/B078VTXSVY
Total Superseded | $88.76 | couplers | $8.00 | 1 | $8.00 | https://www.amazon.com/Coupling-Connector-Coupler-Accessory-Fittings/dp/B08335MYGW
 |  | BTS 7960 | $18.77 | 1 | $18.77 | https://www.amazon.com/JESSINIE-BTN7960-Driver-Arduino-Current/dp/B0C1C3LKKM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
 |  | battery | $35.00 | 1 | $35.00 | https://www.amazon.com/Zeee-Batteries-Connector-Helicopter-Quadcopter/dp/B0972RKJDS
 |  | buck converter | $7.00 | 1 | $7.00 | https://www.amazon.com/Converter-Adjustable-Regulator-Voltmeter-Display%EF%BC%88Pack/dp/B0F1M2SR31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
 |  | XT60 connector | $6.00 | 1 | $6.00 | https://www.amazon.com/TMH-Connector-Female-Connectors-Battery/dp/B0D35B8JWG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
 |  | IMU | $16.00 | 1 | $16.00 | https://www.amazon.com/Gyroscope-Acceleration-Magnetic-Accelerator-Magnetometer/dp/B0B6ZRH4RQ
 |  | Makerbeam Kit | $141.00 | 1 | $141.00 | https://www.amazon.com/MakerBeam-Regular-anodized-including-brackets/dp/B00BBH3LZC
 |  | Flat Urethane Belt | $26.00 | 1 | $26.00 | https://www.amazon.com/Orange-Flat-Urethane-10ft-Section/dp/B0BSVKCQHR
 |  | Flat Urethane Belt 2 | $38.76 | 1 | $38.76 | https://www.amazon.com/dp/B0BSVK8744
 |  | 8mm shafts | $9.00 | 1 | $9.00 | https://www.amazon.com/TOP-VIGOR-Stainless-Steel-Helicopter-Airplane/dp/B0CDQDS1BL?adgrpid=185084441223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
 |  | Camera | $24.00 | 1 | $24.00 | https://www.amazon.com/Seeed-Studio-XIAO-ESP32-Sense/dp/B0C69FFVHH?sp_csd=d2lkZ2V0TmFtZT1zcF9hdGY
 |  | brass Standoff kit | $9.00 | 1 | $9.00 | https://www.amazon.com/Standoff-Threaded-Motherboard-Assortment-Mounting/dp/B06XQ33Y9X
 |  | battery charger | $36.54 | 1 | $36.54 | https://www.amazon.com/B6-Battery-Charger-Discharger-Connectors/dp/B0F2H3XR6S?hvadid=409999371050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
 |  | breadboard jumper wires | $7.00 | 1 | $7.00 | https://www.amazon.com/EDGELEC-Breadboard-Optional-Assorted-Multicolored/dp/B07GD2BWPY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
 |  | soldering Iron kit | $25.00 | 1 | $25.00 | https://www.amazon.com/Soldering-Adjustable-Temperature-Controlled-Thermostatic/dp/B0BYT9S65Y
 |  | solder gun (do not buy) | $27.00 | 0 | $0.00 | https://www.amazon.com/dp/B0DNFCJ77H?sp_csd=d2lkZ2V0TmFtZT1zcF9kZXRhaWxfdGhlbWF0aWM
 |  | Fuses with holders | $8.00 | 1 | $8.00 | https://www.amazon.com/Upgraded-Waterproof-Standard-YNZDRWA-Holders/dp/B0D7D25G62
 |  | Bearings | $7.00 | 1 | $7.00 | https://www.amazon.com/SHKI/dp/B09PKD8QZZ
 |  | RPLidarA2M12 | $280.00 | 1 | $280.00 | https://www.robotshop.com/products/rplidar-a2m12-360-laser-range-scanner
 |  | Raspberry Pi (4gb Ram) | $100.00 | 0 | $0.00 | https://vilros.com/products/raspberry-pi-4-model-b-1?variant=40820184744030
 |  | Raspberry Pi camera mod 3 | $28.00 | 0 | $0.00 | https://www.pishop.us/product/raspberry-pi-camera-module-3/?src=raspberrypi
 |  | m4 screws |  |  |  | https://www.amazon.com/Fgruh-Washers-Assortment-Stainless-Printer/dp/B0FG2D92BV?adgrpid=102083928466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

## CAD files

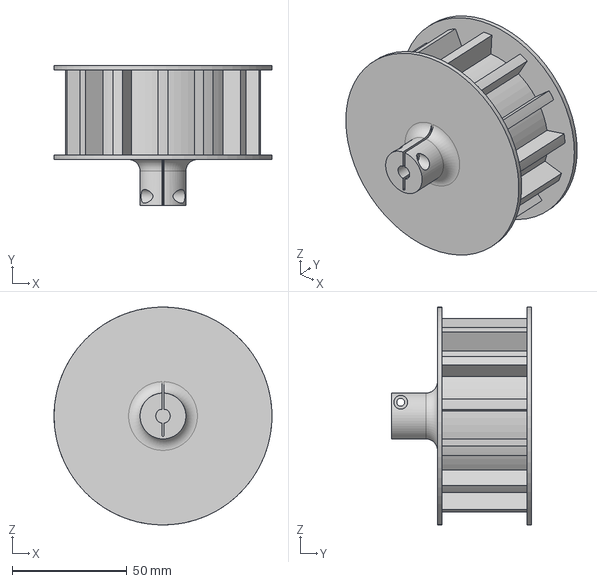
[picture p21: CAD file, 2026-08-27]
cad/Custom_parts/Drive_sprocket.step
95.0 x 61.0 x 95.0 mm

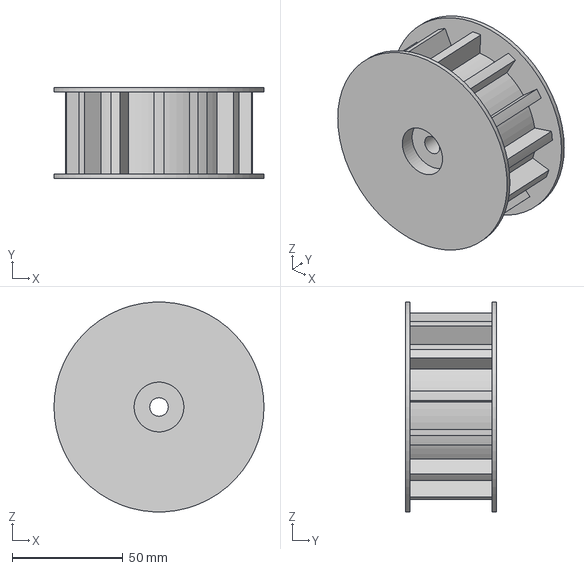
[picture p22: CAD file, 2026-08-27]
cad/Custom_parts/Bearing_sprocket_V2.step
95.0 x 41.0 x 94.9 mm

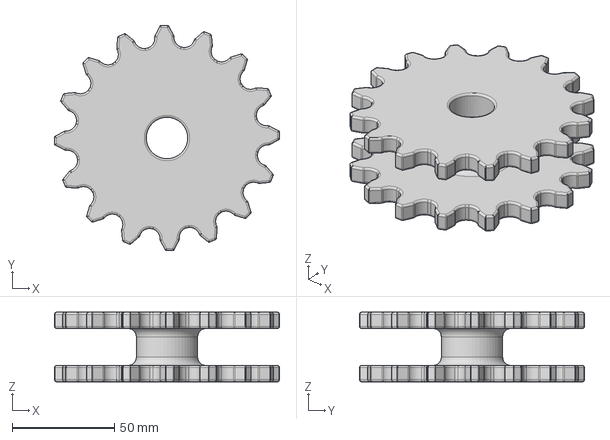
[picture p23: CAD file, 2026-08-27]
cad/Custom_parts/Sprocket_V1.step
110.0 x 110.0 x 34.0 mm

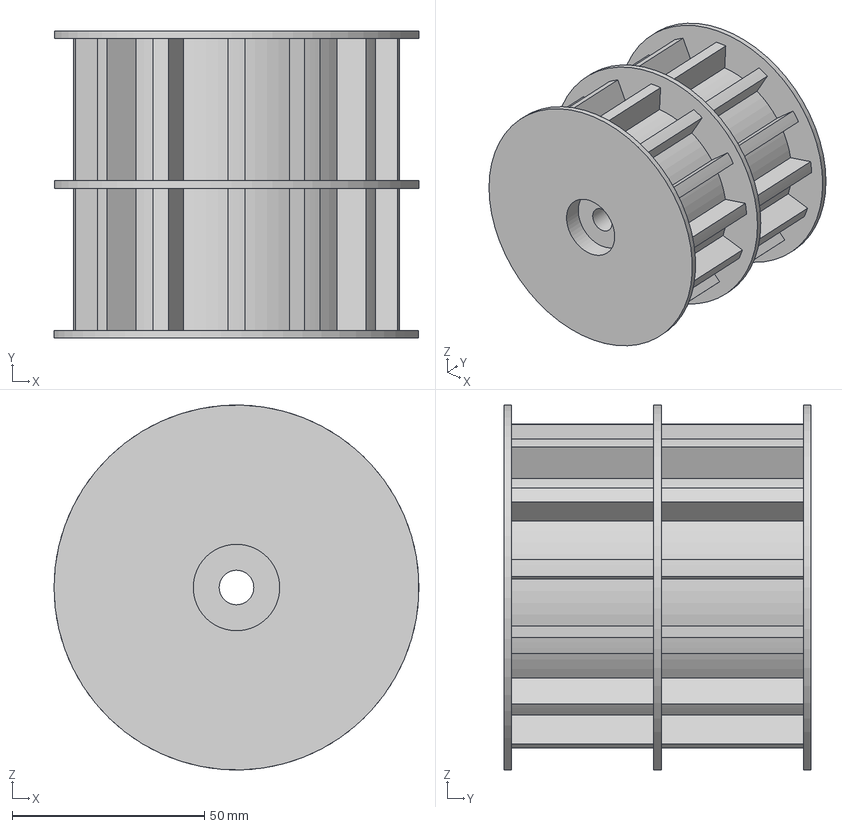
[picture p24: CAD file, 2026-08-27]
cad/Custom_parts/Flipper_sprocket.step
95.0 x 80.0 x 95.0 mm

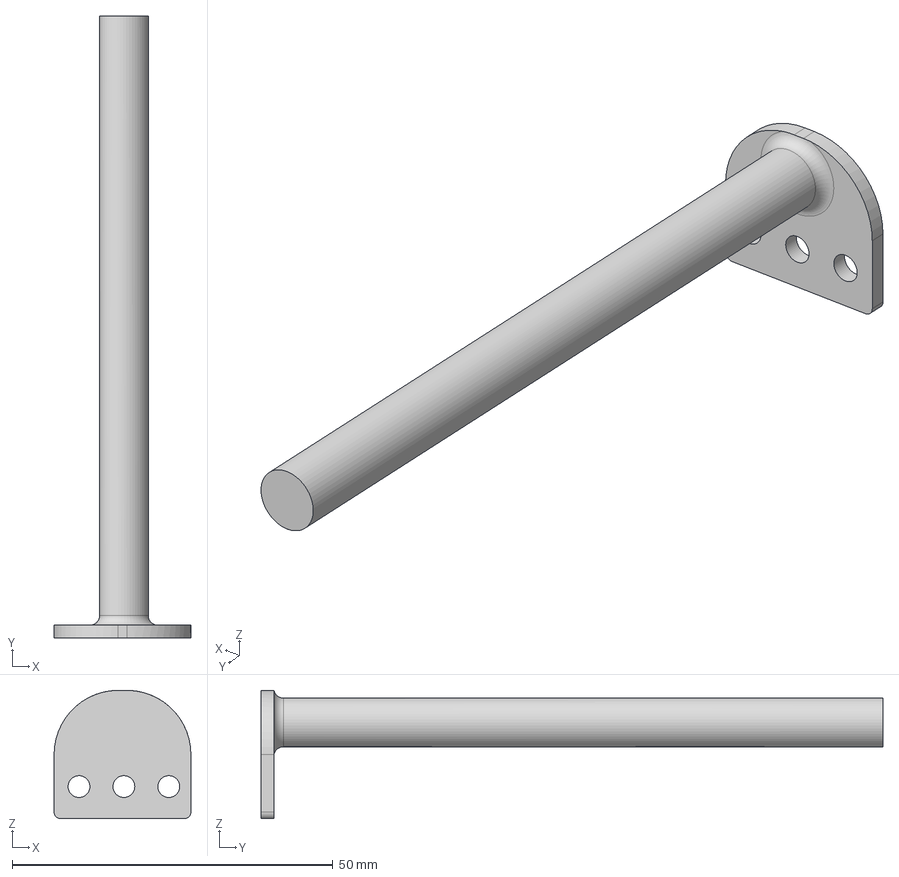
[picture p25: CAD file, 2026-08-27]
cad/Custom_parts/Roller Holder.step
21.3 x 97.0 x 20.0 mm

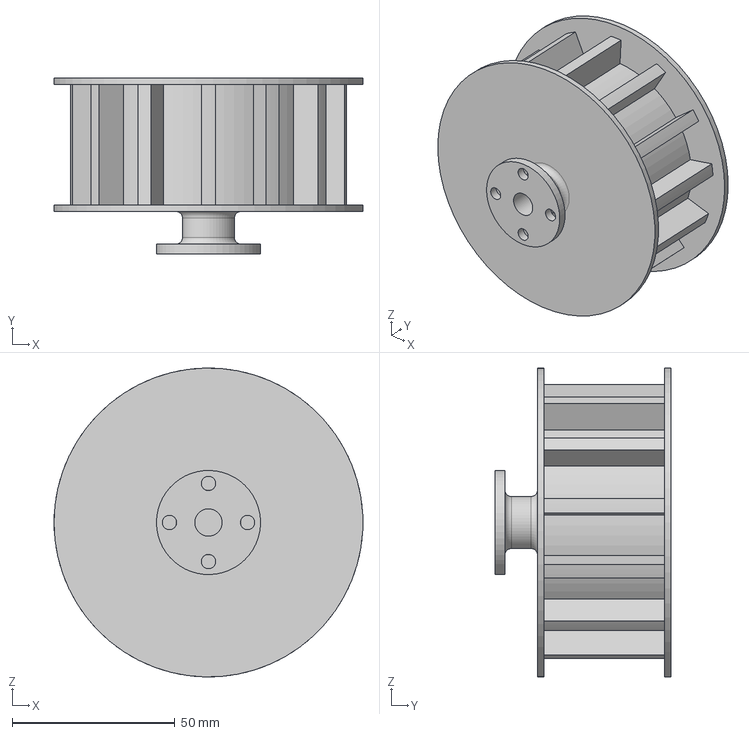
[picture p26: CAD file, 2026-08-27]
cad/Custom_parts/Drive_sprocket_V2_NewCoupler.step
95.0 x 54.0 x 95.0 mm

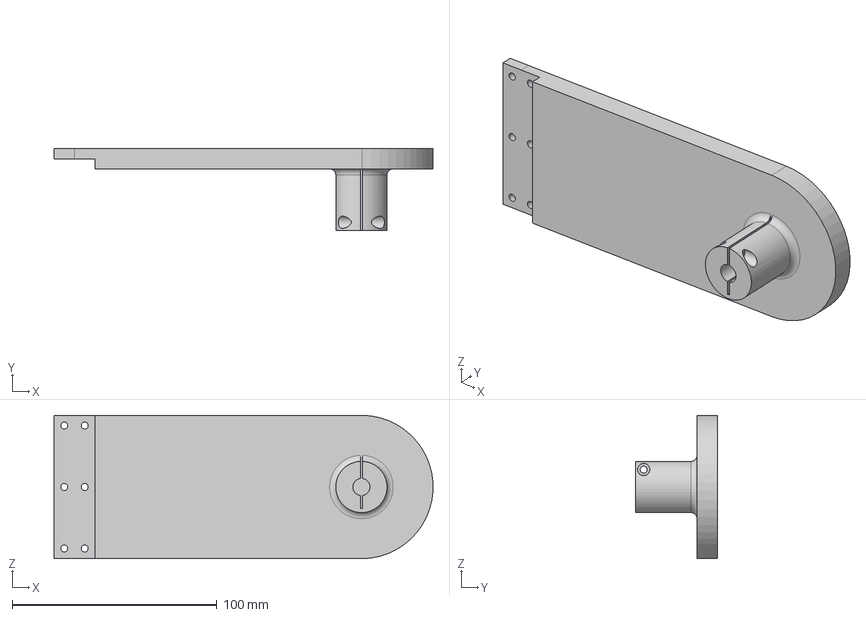
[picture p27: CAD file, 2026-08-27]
cad/Custom_parts/Flipper arm pt 2.step
184.9 x 40.0 x 70.0 mm

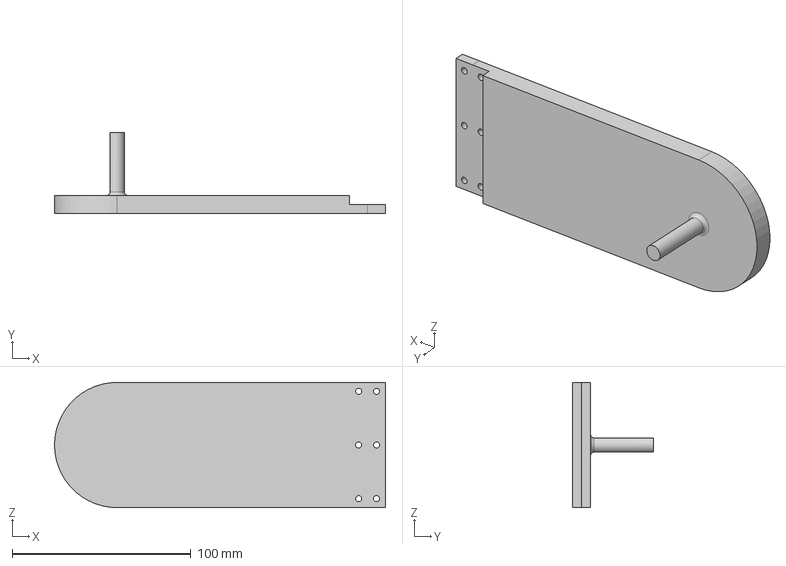
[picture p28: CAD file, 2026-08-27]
cad/Custom_parts/Flipper arm pt 1.step
185.0 x 45.0 x 70.0 mm

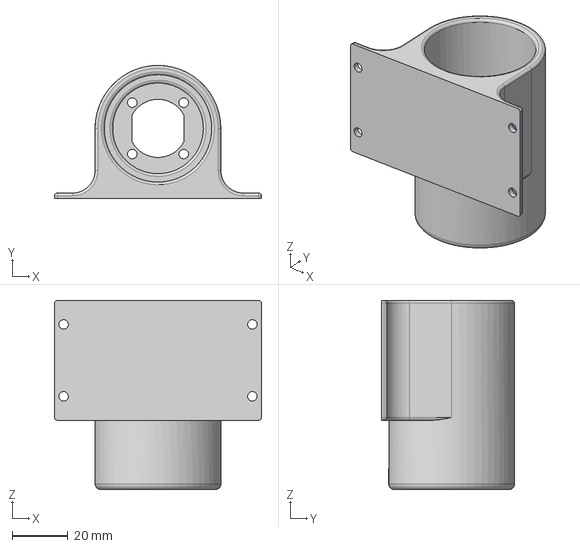
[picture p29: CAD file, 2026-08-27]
cad/Custom_parts/Drive Motor Holder.step
74.0 x 47.6 x 67.6 mm

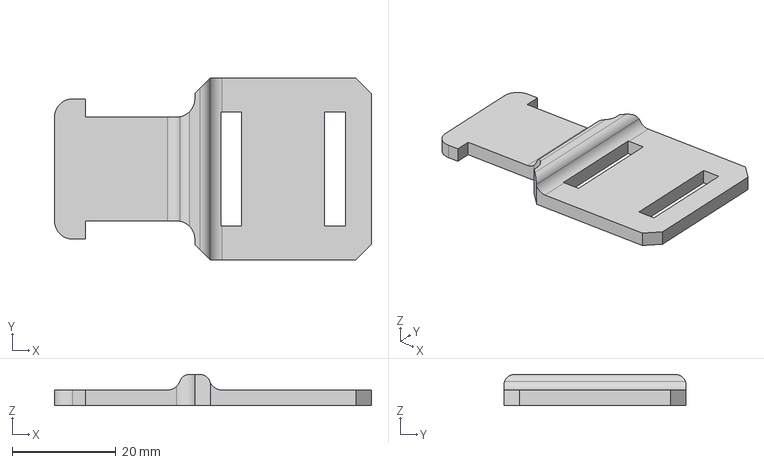
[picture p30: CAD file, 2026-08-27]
cad/Custom_parts/Tread LInk.step
61.0 x 35.0 x 6.00 mm

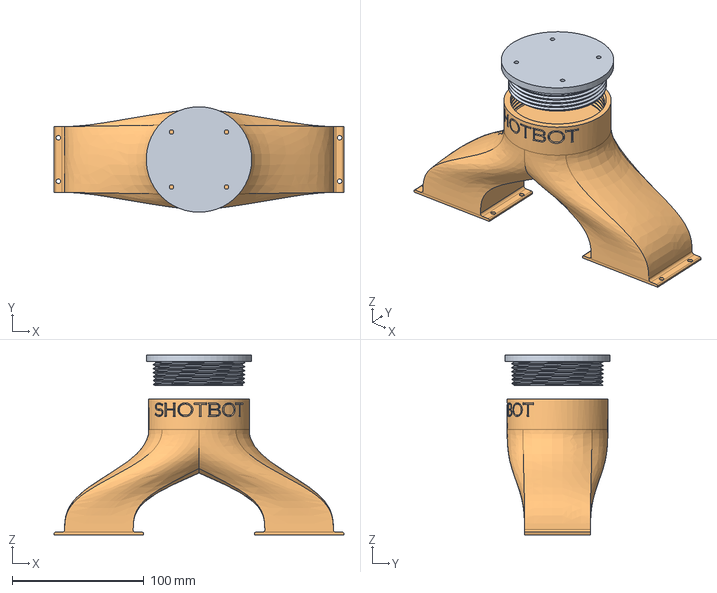
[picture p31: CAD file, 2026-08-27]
cad/Custom_parts/Lidar Mount.step
220.0 x 80.0 x 136.4 mm

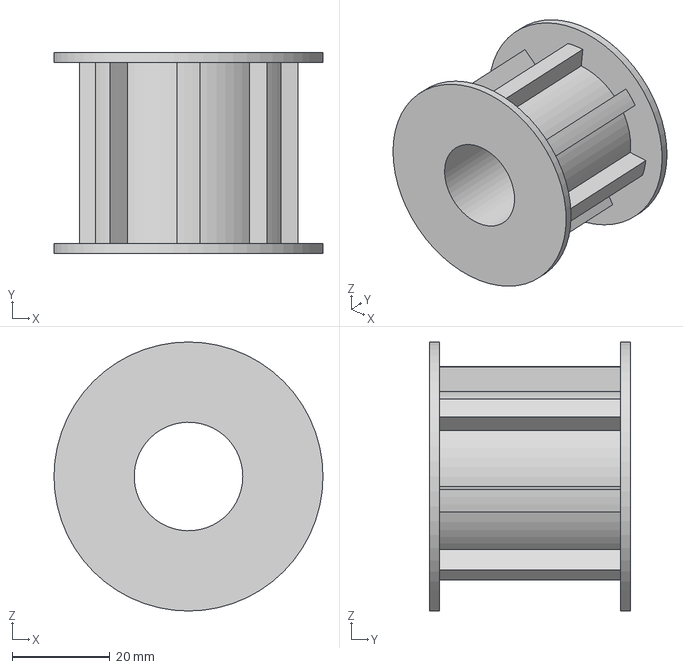
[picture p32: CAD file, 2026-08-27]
cad/Custom_parts/Roller Sprocket.step
55.0 x 41.0 x 55.0 mm

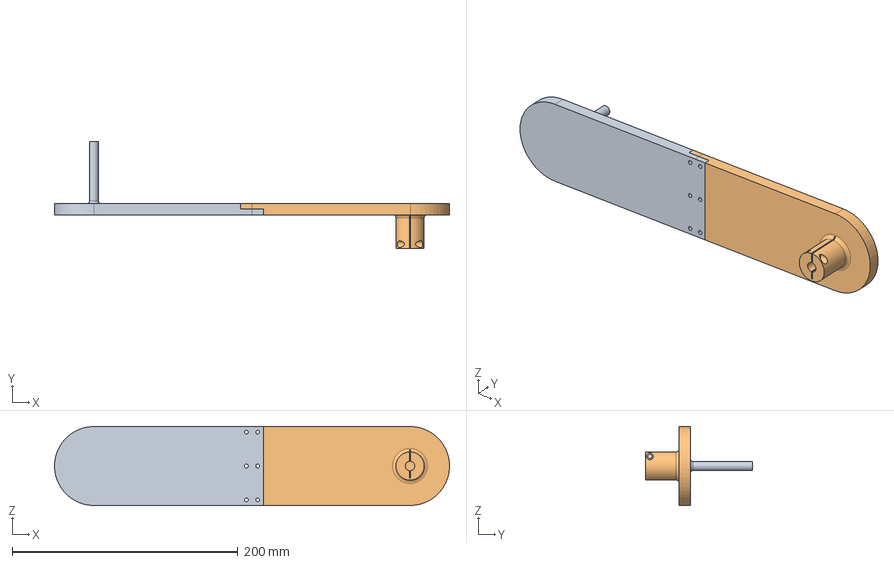
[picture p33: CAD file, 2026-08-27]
cad/Custom_parts/Flipper arm V2.step
349.9 x 95.0 x 70.0 mm

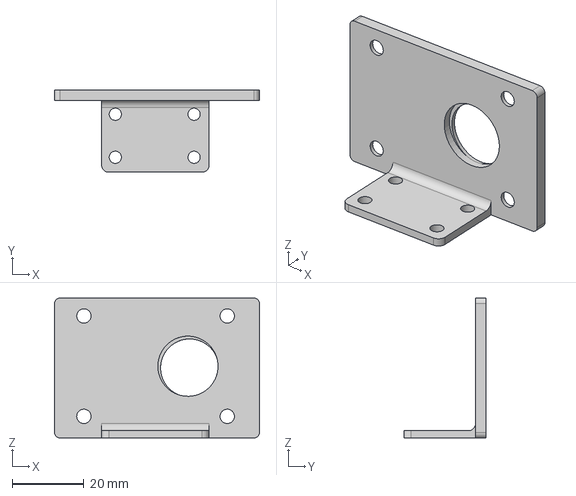
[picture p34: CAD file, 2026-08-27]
cad/Custom_parts/Flipper Motor Bracket Copy.step
57.2 x 23.0 x 39.0 mm
Left Flipper Bracket

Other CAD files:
cad/Custom_parts/Roller Holder V2.step
cad/Custom_parts/Bearing_Sprocket_V1.step
cad/Custom_parts/Flipper+Motor+Bracket+Copy.step
cad/Custom_parts/Flipper+arm+pt+1.step
cad/Custom_parts/Flipper+arm+pt+2.step

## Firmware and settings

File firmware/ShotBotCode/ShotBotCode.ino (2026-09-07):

#include <Bluepad32.h>

// ============================================================================
// ShotBot ESP32 Motor Controller
// ============================================================================
// Controls:
//   - Left drive motor (M1):  Left joystick Y-axis
//   - Right drive motor (M3): Right joystick Y-axis
//   - Front/flipper motor (M2):
//       R1 -> forward
//       L1 -> reverse
//
// Hardware:
//   - ESP32 DevKit
//   - 3x BTS7960 motor drivers
//   - Bluetooth gamepad via Bluepad32
//
// Safety behavior:
//   - Motor drivers remain disabled until a controller is connected.
//   - All motors stop and drivers are disabled if the controller disconnects.
// ============================================================================


// ============================================================================
// Motor Enable Pins
// ============================================================================

constexpr int EN_M1 = 23;  // Left drive motor
constexpr int EN_M2 = 16;  // Front / flipper motor
constexpr int EN_M3 = 17;  // Right drive motor


// ============================================================================
// Motor PWM Pins
// ============================================================================

// M1 - Left drive motor
constexpr int M1_LPWM = 25;
constexpr int M1_RPWM = 26;

// M2 - Front / flipper motor
constexpr int M2_LPWM = 27;
constexpr int M2_RPWM = 14;

// M3 - Right drive motor
constexpr int M3_LPWM = 33;
constexpr int M3_RPWM = 32;


// ============================================================================
// PWM Configuration
// ============================================================================

constexpr int PWM_FREQ = 20000;  // 20 kHz
constexpr int PWM_RES  = 8;      // 8-bit resolution: 0-255

constexpr int MAX_PWM_DRIVE   = 102;  // 40% maximum drive output
constexpr int MAX_PWM_FLIPPER = 255;  // 100% maximum flipper output

// LEDC PWM channels
constexpr int CH_M1_FWD = 0;
constexpr int CH_M1_REV = 1;

constexpr int CH_M3_FWD = 2;
constexpr int CH_M3_REV = 3;

constexpr int CH_M2_FWD = 4;
constexpr int CH_M2_REV = 5;


// ============================================================================
// Controller Configuration
// ============================================================================

constexpr float DRIVE_DEADZONE = 0.08f;
constexpr float GAMEPAD_AXIS_MAX = 512.0f;

constexpr unsigned long LOOP_DELAY_MS = 10;

GamepadPtr pad = nullptr;


// ============================================================================
// Motor Control Functions
// ============================================================================

/**
 * Enable or disable all BTS7960 motor drivers.
 */
void setEnableAll(bool enabled) {
    digitalWrite(EN_M1, enabled ? HIGH : LOW);
    digitalWrite(EN_M2, enabled ? HIGH : LOW);
    digitalWrite(EN_M3, enabled ? HIGH : LOW);
}


/**
 * Command a motor using its forward and reverse LEDC channels.
 *
 * Positive value -> forward
 * Negative value -> reverse
 * Zero           -> stop
 */
void setMotor(int channelForward,
              int channelReverse,
              int value,
              int maxPwm) {

    value = constrain(value, -maxPwm, maxPwm);

    if (value > 0) {
        ledcWrite(channelForward, value);
        ledcWrite(channelReverse, 0);

    } else if (value < 0) {
        ledcWrite(channelForward, 0);
        ledcWrite(channelReverse, -value);

    } else {
        ledcWrite(channelForward, 0);
        ledcWrite(channelReverse, 0);
    }
}


/**
 * Stop all three motors.
 */
void stopAllMotors() {
    setMotor(CH_M1_FWD, CH_M1_REV, 0, MAX_PWM_DRIVE);
    setMotor(CH_M3_FWD, CH_M3_REV, 0, MAX_PWM_DRIVE);
    setMotor(CH_M2_FWD, CH_M2_REV, 0, MAX_PWM_FLIPPER);
}


/**
 * Remove small joystick inputs around the neutral position.
 */
float applyDeadzone(float value, float deadzone) {
    if (fabs(value) < deadzone) {
        return 0.0f;
    }

    return value;
}


// ============================================================================
// Bluepad32 Callbacks
// ============================================================================

void onConnectedGamepad(GamepadPtr gamepad) {
    pad = gamepad;

    Serial.println("Controller connected.");

    setEnableAll(true);
}


void onDisconnectedGamepad(GamepadPtr gamepad) {
    if (pad == gamepad) {
        pad = nullptr;
    }

    Serial.println("Controller disconnected.");

    stopAllMotors();
    setEnableAll(false);
}


// ============================================================================
// Setup
// ============================================================================

void setup() {
    Serial.begin(115200);

    // Configure motor-driver enable pins.
    pinMode(EN_M1, OUTPUT);
    pinMode(EN_M2, OUTPUT);
    pinMode(EN_M3, OUTPUT);

    // Keep motor drivers disabled during startup.
    setEnableAll(false);

    // Configure LEDC PWM channels.
    ledcSetup(CH_M1_FWD, PWM_FREQ, PWM_RES);
    ledcSetup(CH_M1_REV, PWM_FREQ, PWM_RES);

    ledcSetup(CH_M3_FWD, PWM_FREQ, PWM_RES);
    ledcSetup(CH_M3_REV, PWM_FREQ, PWM_RES);

    ledcSetup(CH_M2_FWD, PWM_FREQ, PWM_RES);
    ledcSetup(CH_M2_REV, PWM_FREQ, PWM_RES);

    // Attach ESP32 GPIO pins to their respective PWM channels.
    ledcAttachPin(M1_LPWM, CH_M1_FWD);
    ledcAttachPin(M1_RPWM, CH_M1_REV);

    ledcAttachPin(M3_LPWM, CH_M3_FWD);
    ledcAttachPin(M3_RPWM, CH_M3_REV);

    ledcAttachPin(M2_LPWM, CH_M2_FWD);
    ledcAttachPin(M2_RPWM, CH_M2_REV);

    stopAllMotors();

    // Initialize Bluetooth controller support.
    BP32.setup(&onConnectedGamepad, &onDisconnectedGamepad);

    Serial.println("Bluepad32 ready. Pair a controller to begin.");
}


// ============================================================================
// Main Loop
// ============================================================================

void loop() {
    BP32.update();

    // Fail-safe: stop and disable all motors when no controller is connected.
    if (!pad || !pad->isConnected()) {
        stopAllMotors();
        setEnableAll(false);

        delay(LOOP_DELAY_MS);
        return;
    }

    setEnableAll(true);


    // ------------------------------------------------------------------------
    // Drive Control
    //
    // Tank drive:
    //   Left joystick Y-axis  -> M1
    //   Right joystick Y-axis -> M3
    // ------------------------------------------------------------------------

    const int leftAxis  = pad->axisY();
    const int rightAxis = pad->axisRY();

    float leftCommand  = leftAxis / GAMEPAD_AXIS_MAX;
    float rightCommand = rightAxis / GAMEPAD_AXIS_MAX;

    leftCommand  = applyDeadzone(leftCommand, DRIVE_DEADZONE);
    rightCommand = applyDeadzone(rightCommand, DRIVE_DEADZONE);

    leftCommand  = constrain(leftCommand, -1.0f, 1.0f);
    rightCommand = constrain(rightCommand, -1.0f, 1.0f);

    const int m1Pwm = static_cast<int>(leftCommand * MAX_PWM_DRIVE);
    const int m3Pwm = static_cast<int>(rightCommand * MAX_PWM_DRIVE);

    setMotor(CH_M1_FWD, CH_M1_REV, m1Pwm, MAX_PWM_DRIVE);
    setMotor(CH_M3_FWD, CH_M3_REV, m3Pwm, MAX_PWM_DRIVE);


    // ------------------------------------------------------------------------
    // Front / Flipper Control
    //
    // R1 -> forward at full PWM
    // L1 -> reverse at full PWM
    // Both or neither -> stop
    // ------------------------------------------------------------------------

    const bool r1Pressed = pad->r1();
    const bool l1Pressed = pad->l1();

    int m2Pwm = 0;

    if (r1Pressed && !l1Pressed) {
        m2Pwm = MAX_PWM_FLIPPER;

    } else if (l1Pressed && !r1Pressed) {
        m2Pwm = -MAX_PWM_FLIPPER;
    }

    setMotor(CH_M2_FWD, CH_M2_REV, m2Pwm, MAX_PWM_FLIPPER);

    delay(LOOP_DELAY_MS);
}

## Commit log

2026-08-27 Cad updates
    Adding CAD files including assemblies, renders, and parts
    [Bearing_Sprocket_V1.step, Bearing_sprocket_V2.step, Drive Motor Holder.step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]
2026-08-27 Update README.md
    updated cad\readme
2026-08-31 electrical updates
    finishing the electrical section of the repo
    [Sheet1.SchDoc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]
2026-09-07 remove software folder and add documentation
    [Shotbot_BOM.xlsx]
